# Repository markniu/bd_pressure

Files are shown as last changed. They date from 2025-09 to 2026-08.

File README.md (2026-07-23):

#  Auto PA Calibration


## Overview 

Pressure Advance (PA) is one of the most impactful tuning parameters in FDM printing, yet calibrating it correctly is time-consuming, requires print-specific expertise, and must be repeated whenever filament, speed, or temperature changes.

**bd_pressure** solves this with a dedicated strain-gauge sensor module that measures extruder pressure directly — without printing a single line. It runs an automated calibration routine by simulating extrusion pressure behaviour during acceleration and deceleration, then reports the optimal PA value to the printer firmware over USB or I2C.

The same hardware doubles as a high-precision nozzle probe for bed levelling, acting as a drop-in switch-type endstop on the Z− pin.

 
 
---

<a href="https://www.youtube.com/watch?v=r0qmRdhEHUw">
  
</a>




---

## Features

| Feature | Description |
|---|---|
| **Automatic PA calibration** | No calibration prints. Extruder-only routine measures pressure response directly. |
| **Nozzle probe** | Strain-gauge contact detection for Z homing, Z tilt, bed mesh or work with eddy bed scan sensor. |
| **EMI immunity** | Sensor mounted zero-distance to PCB — minimal analog trace length eliminates noise pickup. |
| **USB & I2C** | Flexible host connectivity; works with Klipper and compatible setups. |
| **Broad compatibility** | Mounting footprint compatible with E3D and Voron toolhead ecosystems. |

---

## How It Works

### Mode 1 — Pressure Advance Calibration

Rather than printing calibration patterns and analysing them visually, bd_pressure directly measures the mechanical relationship between extruder motor acceleration and filament pressure at the nozzle.

1. The extruder motor runs a controlled acceleration/deceleration sequence.
2. The strain gauge measures the resulting force in real time.
3. The on-board MCU fits a pressure-vs-acceleration curve and derives the optimal PA value.
4. The result is sent to the printer firmware via USB or I2C.

This approach is conceptually similar to the automated calibration used in the Bambu Lab A1, but uses a **strain gauge** rather than an eddy current sensor — providing a direct force measurement.

### Mode 2 — Nozzle Probe

bd_pressure operates as a standard switch-type endstop sensor:

1. The printer issues a normal Z homing move.
2. As the nozzle contacts the bed, the strain gauge detects the resulting force change.
3. The module asserts a signal on the endstop output — compatible with any mainboard Z− pin.
4. No additional firmware plugin is required for basic probe operation.

---

## Installation & Documentation
 
Full installation guide, wiring diagrams, and Klipper configuration reference:

 Klipper:
**[pandapi3d.cn/en/bdpressure/home](https://pandapi3d.cn/en/bdpressure/home)**

  RepRapFirmware:
**[github.com/jaysuk](https://github.com/jaysuk/bd_pressure_dwc_plugin)**






 
 The strain gauge sensor: BF350-1EB  350Ω 5.6*4.6mm 
 
---
 
## Community & Support
 
| Channel | Link |
|---|---|
| Discord | [discord.gg/z6ahddnGVU](https://discord.gg/z6ahddnGVU) |
| Facebook group | [facebook.com/groups/380795976169477](https://facebook.com/groups/380795976169477) |
| Thingiverse | [thingiverse](https://www.thingiverse.com/thing:7338066) |
| printables  | [printables](https://www.printables.com/model/1760110-a4t-cowling-variations-for-bdpressure-dragon-drago)
| Where to buy | 🇺🇸 [fabreeko.com](https://fabreeko.com) <br> 🇺🇸 [west3d.com](https://west3d.com) <br> 🌏 [pandapi3d.com](https://pandapi3d.com) <br> 🇨🇳 [淘宝](https://shop62248922.taobao.com/) <br> 🇩🇰 [3do.dk](https://3do.dk/12-abl-probe) |
---

 ### Does PA need to be calibrated during printing?

Not necessarily. Testing shows that manual calibration under actual printing conditions produces nearly the same optimal PA value as automatic calibration in free air. Back pressure and toolhead movement add noise to the pressure data, but the balance point—and therefore the optimal PA value—remains essentially unchanged.

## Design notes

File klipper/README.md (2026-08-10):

## klipper 

#### 1. Install software module
```
cd  ~
git clone https://github.com/markniu/bd_pressure.git
chmod 777 ~/bd_pressure/klipper/install.sh
~/bd_pressure/klipper/install.sh
```

#### 2. Configure Klipper

Add [include bd_pressure.cfg] into the printer.cfg , and modify the pins to your actual use in the section [probe] and [bdpressure bd_pa]

#### 3. OrcaSlicer:

1. Disable the Pressure advance in the Material settings.

2. Add the following G-code lines into the beginning of the Start_Gcode in the slicer, then it will do pressure advance calibration with your setting and automatically set the right PA value. 
```
G28                    ; Home all the axis
G1 Z30                 ; raise the nozzle above the bed
PA_CALIBRATE NOZZLE_TEMP=[nozzle_temperature] MAX_VOLUMETRIC=[filament_max_volumetric_speed] ACC_WALL=[outer_wall_acceleration]  TRAVEL_SPEED=[travel_speed]  ACC_TO_DECEL_FACTOR=[accel_to_decel_factor] NOZZLE=[nozzle_diameter] FLOW=[filament_flow_ratio]
```
`PA_CALIBRATE` only shifts the pattern's starting point to the smallest valid coordinates (x_min/y_min + `X_MARGIN`/`Y_MARGIN`, default 5 mm); the movement distances are unchanged (80 mm line = 20/40/20 mm, Y step 3.5 mm × 50 passes). This removes the old hard-coded X78/Y38.75 offset, so the same pattern fits smaller XY machines too. `NOZZLE=[nozzle_diameter]` and `FLOW=[filament_flow_ratio]` scale the extrusion amounts for your nozzle size and slicer flow ratio (the built-in E values are for a 0.4 mm nozzle at 100 % flow). NOTE: OrcaSlicer's flow-ratio placeholder is `[filament_flow_ratio]` (the config key is `filament_flow_ratio`); `[filament_flow]` only exists in PrusaSlicer and will cause "Variable does not exist" in Orca.

Manual example (run after homing / raising Z):
```
PA_CALIBRATE NOZZLE_TEMP=210 MAX_VOLUMETRIC=20 ACC_WALL=4000 TRAVEL_SPEED=400 ACC_TO_DECEL_FACTOR=50% NOZZLE=0.4 FLOW=1.0
```

If the fixed pattern still exceeds your machine (e.g. a 120 mm bed), reduce it explicitly, e.g. `PASSES=30` or `Y_STEP=2.5`:

#### 3. Prusa Slicer:
```
G28                    ; Home all the axis
G1 Z30                 ; raise the nozzle above the bed
PA_CALIBRATE NOZZLE_TEMP=[temperature] MAX_VOLUMETRIC=[filament_max_volumetric_speed] ACC_WALL=[outer_wall_acceleration]  TRAVEL_SPEED=[travel_speed]  MINIMUM_CRUISE_RATIO=0.5 NOZZLE=[nozzle_diameter] FLOW=[extrusion_multiplier] #ACC_TO_DECEL_FACTOR=[accel_to_decel_factor] this klipper specifc variable was replaced in Klipper with MINIMUM_CRUISE_SPEED. and the 0.5 is the default 50% which can be adjusted to suite the printer's capabilities. 
```
NOTE: PrusaSlicer's flow-multiplier placeholder is `[extrusion_multiplier]` (Filament → Advanced → "Extrusion multiplier", config key `extrusion_multiplier`); there is no `[filament_flow]` in PrusaSlicer.
Optional overrides: `X_MARGIN=5 Y_MARGIN=5 Y_STEP=3.5 PASSES=50` (the macro auto-fits them to the machine's travel).

#### bd_pressure.cfg considerations:
If you have both a bd_pressure and as well bd_width, each has the same by-id UUID because of this, each plugin will try and take control of the first device it can see with the UUID for the USB example 
So you would:
unplug bd_pressure usb cable, then use ls /dev/serial/by-path and take note of the entries there, then plug it back in and use the new entry that appears in place of the "ReplaceWithYourDevicePath" in the example below. 
you will only have to repeat this process if you change what port the bd_pressure is plugged into.
as well you will need to do this in bd_width.cfg as well as both devices will still show the by-id string and can still select the wrong device. 

##   usb example 
# port:usb
# serial:/dev/serial/by-id/usb-1a86_USB_Serial-if00-port0  ## uncomment this if you only have bd_pressure an no bd_width device
# serial:/dev/serial/by-path/ReplaceWithYourDevicePath  # Uncomment this if you have both bd_pressure and bd_width. You need to use ls /dev/serial/by-path , and determine which entry belongs to bd_pressure. 
#if you change the port it's plugged into, you will need to adjust this after doing so to reflect the new usb port you moved it to. 
#you also repeat this with bd_width.cfg to resolve the conflict.
# baud:38400

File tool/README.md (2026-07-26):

### BD Pressure Monitor – Quick Guide

1. Setup: Select COM port & baud (default 38400) → Connect. Auto-sends d; to start streaming.
2. Plot: Live waveform. Use Window slider for time range, toggle Auto Y scale. Pause to freeze, Clear to reset.
3. Serial Response Box: Shows all raw incoming and outgoing data (including command echo and sensor values).
4. Supported Quick Commands (BD Firmware Specific)

| Button | Command | Function |
|---|---|---|
| Endstop | e; | Switch to Endstop / Probe mode |
| Raw on | d; | Enable continuous ADC data output (sent automatically on connect) |
| Raw off | D; | Disable data output |
| PA mode | l; | Switch to Pressure Advance mode |
| Normal | i; | Set normal polarity |
| Inverted | I; | Set inverted polarity |
| Set normal | N; | Use the current reading as the baseline (zero point) |

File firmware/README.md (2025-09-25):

# Firmware Download into the sensor

1. Press and Hold on the boot button on the sensor
2. Power on the sensor with usb cable
3. Release the boot button
4. Open the STM32CubeProgrammer.exe
5. Choose the UART port and click connect button in the STM32CubeProgrammer
6. Open the firmware file for example: BD_PA20250925.hex --> Click Download
7. Finish

This process is the same as bdwidth sensor, here is the video of bdwidth: https://youtu.be/c74Q1chOo8M

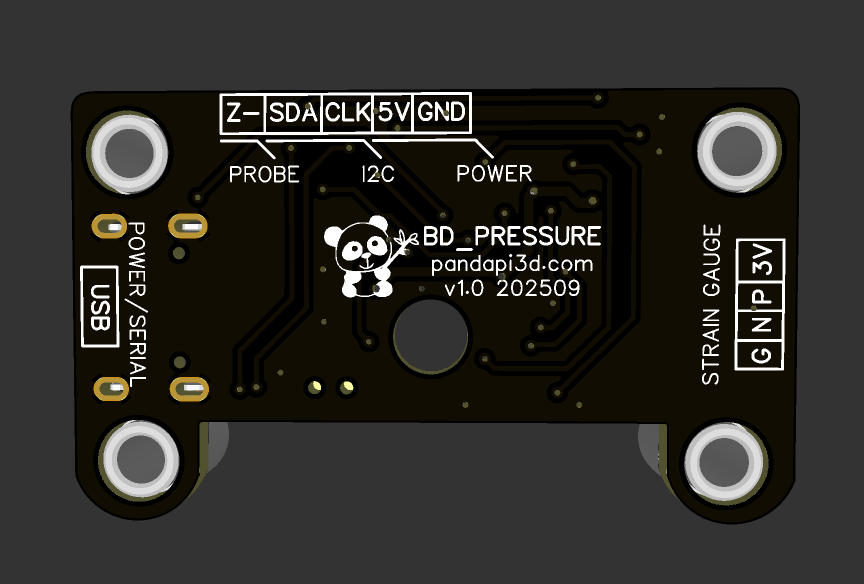
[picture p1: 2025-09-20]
hardware/pcb1.jpg

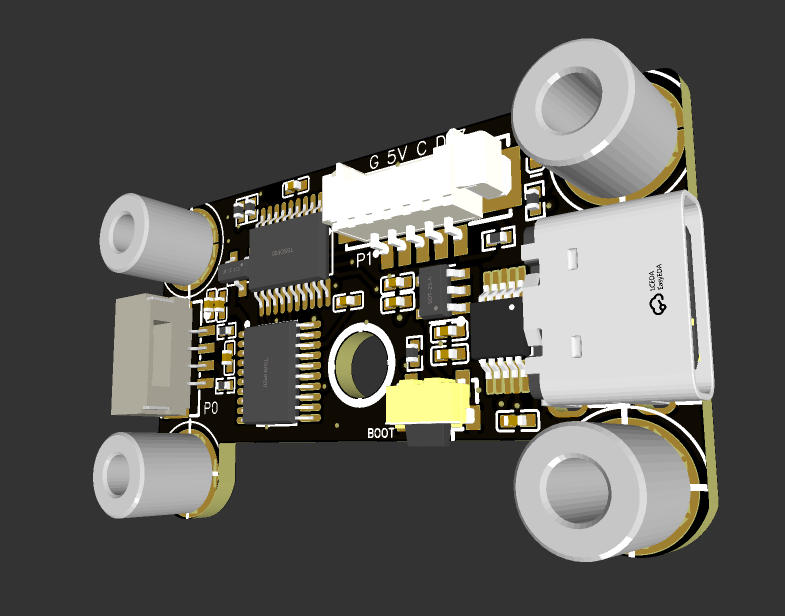
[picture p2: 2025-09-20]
hardware/pcb0.jpg

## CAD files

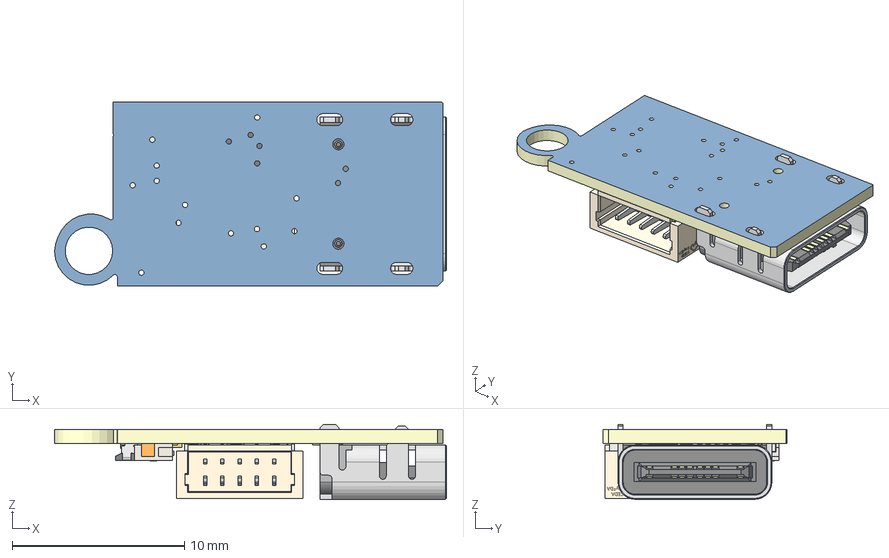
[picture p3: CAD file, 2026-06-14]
CAD/bdpressureE/bd_PCB Daughterboard only.step
22.8 x 10.7 x 4.36 mm
0402~32fe2cf9314f444ca2785a33c2db7189~xBoQ x 3
Board~xBoQ
C3~0402~32fe2cf9314f444ca2785a33c2db7189~xBoQ <1>
0402~~xBoQ
SMD,P=0.5mm,??~ddfed297a0634113a6787db35b523873~xBoQ
SMD,P=0.5mm,??~ddfed297a0634113a6787db35b523873~xBoQ_1
SMD,P=0.5mm,??~ddfed297a0634113a6787db35b523873~xBoQ_2
SMD,P=0.5mm,??~ddfed297a0634113a6787db35b523873~xBoQ_3
SMD,P=0.5mm,??~ddfed297a0634113a6787db35b523873~xBoQ_4
SMD,P=0.5mm,??~ddfed297a0634113a6787db35b523873~xBoQ_5
SMD,P=0.5mm,??~ddfed297a0634113a6787db35b523873~xBoQ_6
SMD,P=0.5mm,??~ddfed297a0634113a6787db35b523873~xBoQ_7
SMD,P=0.5mm,??~ddfed297a0634113a6787db35b523873~xBoQ_8
SMD,P=0.5mm,??~ddfed297a0634113a6787db35b523873~xBoQ_9
SMD,P=0.5mm,??~ddfed297a0634113a6787db35b523873~xBoQ_10
SMD,P=0.5mm,??~ddfed297a0634113a6787db35b523873~xBoQ_11
SMD~7b2b5bea24f944ca8310215fac973989~xBoQ
SMD~7b2b5bea24f944ca8310215fac973989~xBoQ_1
SMD~7b2b5bea24f944ca8310215fac973989~xBoQ_2
SMD~7b2b5bea24f944ca8310215fac973989~xBoQ_3
SMD~7b2b5bea24f944ca8310215fac973989~xBoQ_4
SMD~7b2b5bea24f944ca8310215fac973989~xBoQ_5
SMD~7b2b5bea24f944ca8310215fac973989~xBoQ_6
SMD~7b2b5bea24f944ca8310215fac973989~xBoQ_7
SMD~7b2b5bea24f944ca8310215fac973989~xBoQ_8
SMD~7b2b5bea24f944ca8310215fac973989~xBoQ_9
SMD~7b2b5bea24f944ca8310215fac973989~xBoQ_10
SMD~7b2b5bea24f944ca8310215fac973989~xBoQ_11
SMD~7b2b5bea24f944ca8310215fac973989~xBoQ_12
SMD~7b2b5bea24f944ca8310215fac973989~xBoQ_13
SMD~7b2b5bea24f944ca8310215fac973989~xBoQ_14
SMD~7b2b5bea24f944ca8310215fac973989~xBoQ_15
SMD~7b2b5bea24f944ca8310215fac973989~xBoQ_16
SMD~7b2b5bea24f944ca8310215fac973989~xBoQ_17
SMD~7b2b5bea24f944ca8310215fac973989~xBoQ_18
SMD~7b2b5bea24f944ca8310215fac973989~xBoQ_19
SMD~7b2b5bea24f944ca8310215fac973989~xBoQ_20
SMD~7b2b5bea24f944ca8310215fac973989~xBoQ_21
SMD~7b2b5bea24f944ca8310215fac973989~xBoQ_22
SMD~7b2b5bea24f944ca8310215fac973989~xBoQ_23
SMD~7b2b5bea24f944ca8310215fac973989~xBoQ_24
SMD~7b2b5bea24f944ca8310215fac973989~xBoQ_25
SMD~7b2b5bea24f944ca8310215fac973989~xBoQ_26
SMD~7b2b5bea24f944ca8310215fac973989~xBoQ_27
SMD~7b2b5bea24f944ca8310215fac973989~xBoQ_28
SMD,P=1mm,??~c6a442e2b039451e831f39353c9d0415~xBoQ
SMD,P=1mm,??~c6a442e2b039451e831f39353c9d0415~xBoQ_1
SMD,P=1mm,??~c6a442e2b039451e831f39353c9d0415~xBoQ_2
SMD,P=1mm,??~c6a442e2b039451e831f39353c9d0415~xBoQ_3
SMD,P=1mm,??~c6a442e2b039451e831f39353c9d0415~xBoQ_4
SMD,P=1mm,??~c6a442e2b039451e831f39353c9d0415~xBoQ_5
SMD,P=1mm,??~c6a442e2b039451e831f39353c9d0415~xBoQ_6
SMD,P=1mm,??~c6a442e2b039451e831f39353c9d0415~xBoQ_7
MSOP-10~a8ab40c7a7c54773a59b712bf86c7131~xBoQ
MSOP-10~a8ab40c7a7c54773a59b712bf86c7131~xBoQ_1
MSOP-10~a8ab40c7a7c54773a59b712bf86c7131~xBoQ_2
MSOP-10~a8ab40c7a7c54773a59b712bf86c7131~xBoQ_3
MSOP-10~a8ab40c7a7c54773a59b712bf86c7131~xBoQ_4
MSOP-10~a8ab40c7a7c54773a59b712bf86c7131~xBoQ_5
MSOP-10~a8ab40c7a7c54773a59b712bf86c7131~xBoQ_6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

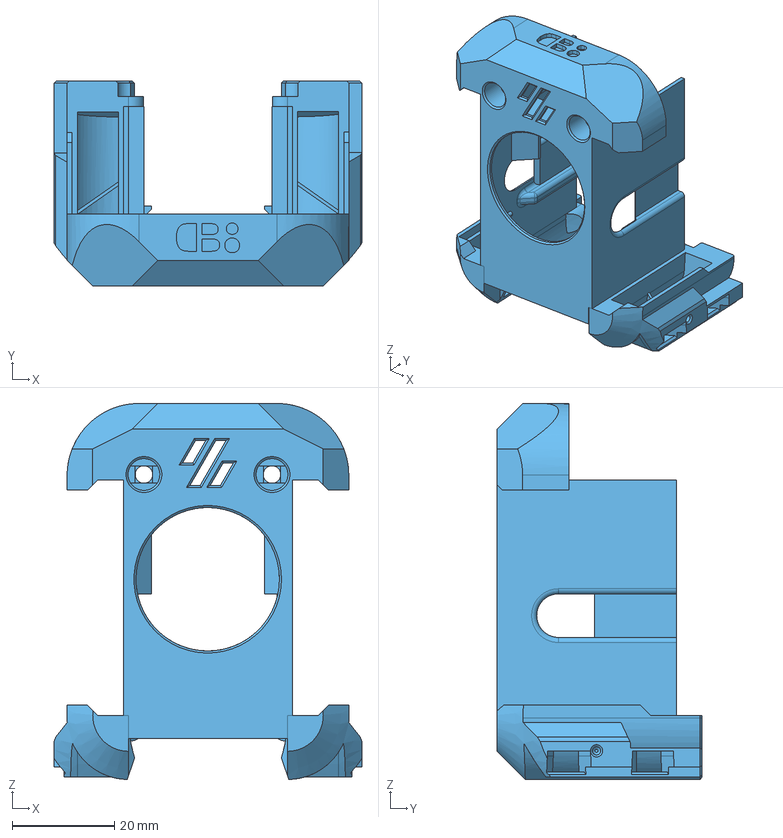
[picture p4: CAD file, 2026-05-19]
CAD/Dragon Burner Cowling By Mark Yue/BD_Pressure_DB_Cowling.step
60.1 x 40.1 x 73.4 mm

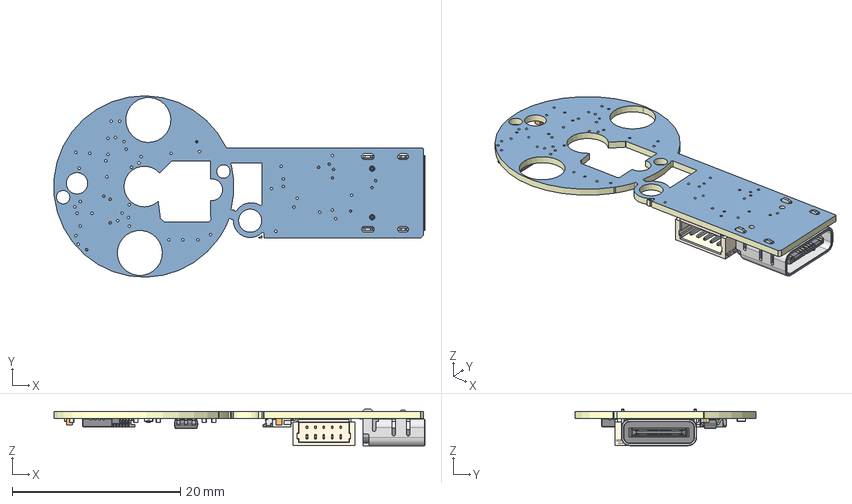
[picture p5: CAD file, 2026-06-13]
CAD/bdpressureE/bd_PCB.step
44.1 x 21.6 x 4.36 mm
0402~32fe2cf9314f444ca2785a33c2db7189~xBoQ x 9
Board~xBoQ x 2
0402~026a4a15ab5c4a92ac0e421d6d013717~xBoQ x 12
0402~~xBoQ x 2
UFQFPN-20(3x3)~ea96fbc26dda4730b9eb4e4342e704ea~xBoQ
SMD,P=0.5mm,??~ddfed297a0634113a6787db35b523873~xBoQ x 24
VQFN-16-EP(3.5x3.5)~b971549606df466cb844ddff3ea6f088~xBoQ x 31
SOT-23-5~460193f9bf2d42e58cf3c2f675b07dc6~xBoQ x 19
SMD~7b2b5bea24f944ca8310215fac973989~xBoQ x 29
SMD,P=1mm,??~c6a442e2b039451e831f39353c9d0415~xBoQ x 8
MSOP-10~a8ab40c7a7c54773a59b712bf86c7131~xBoQ x 14

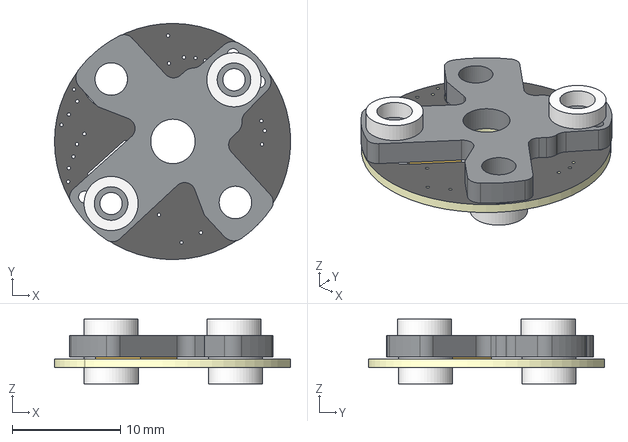
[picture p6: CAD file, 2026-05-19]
CAD/bdpressureE/bdpressure.step
21.8 x 21.8 x 6.00 mm

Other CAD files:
STLs/Dragon Burner Cowling By Mark Yue/BD_Pressure_DB_Cowling.stl

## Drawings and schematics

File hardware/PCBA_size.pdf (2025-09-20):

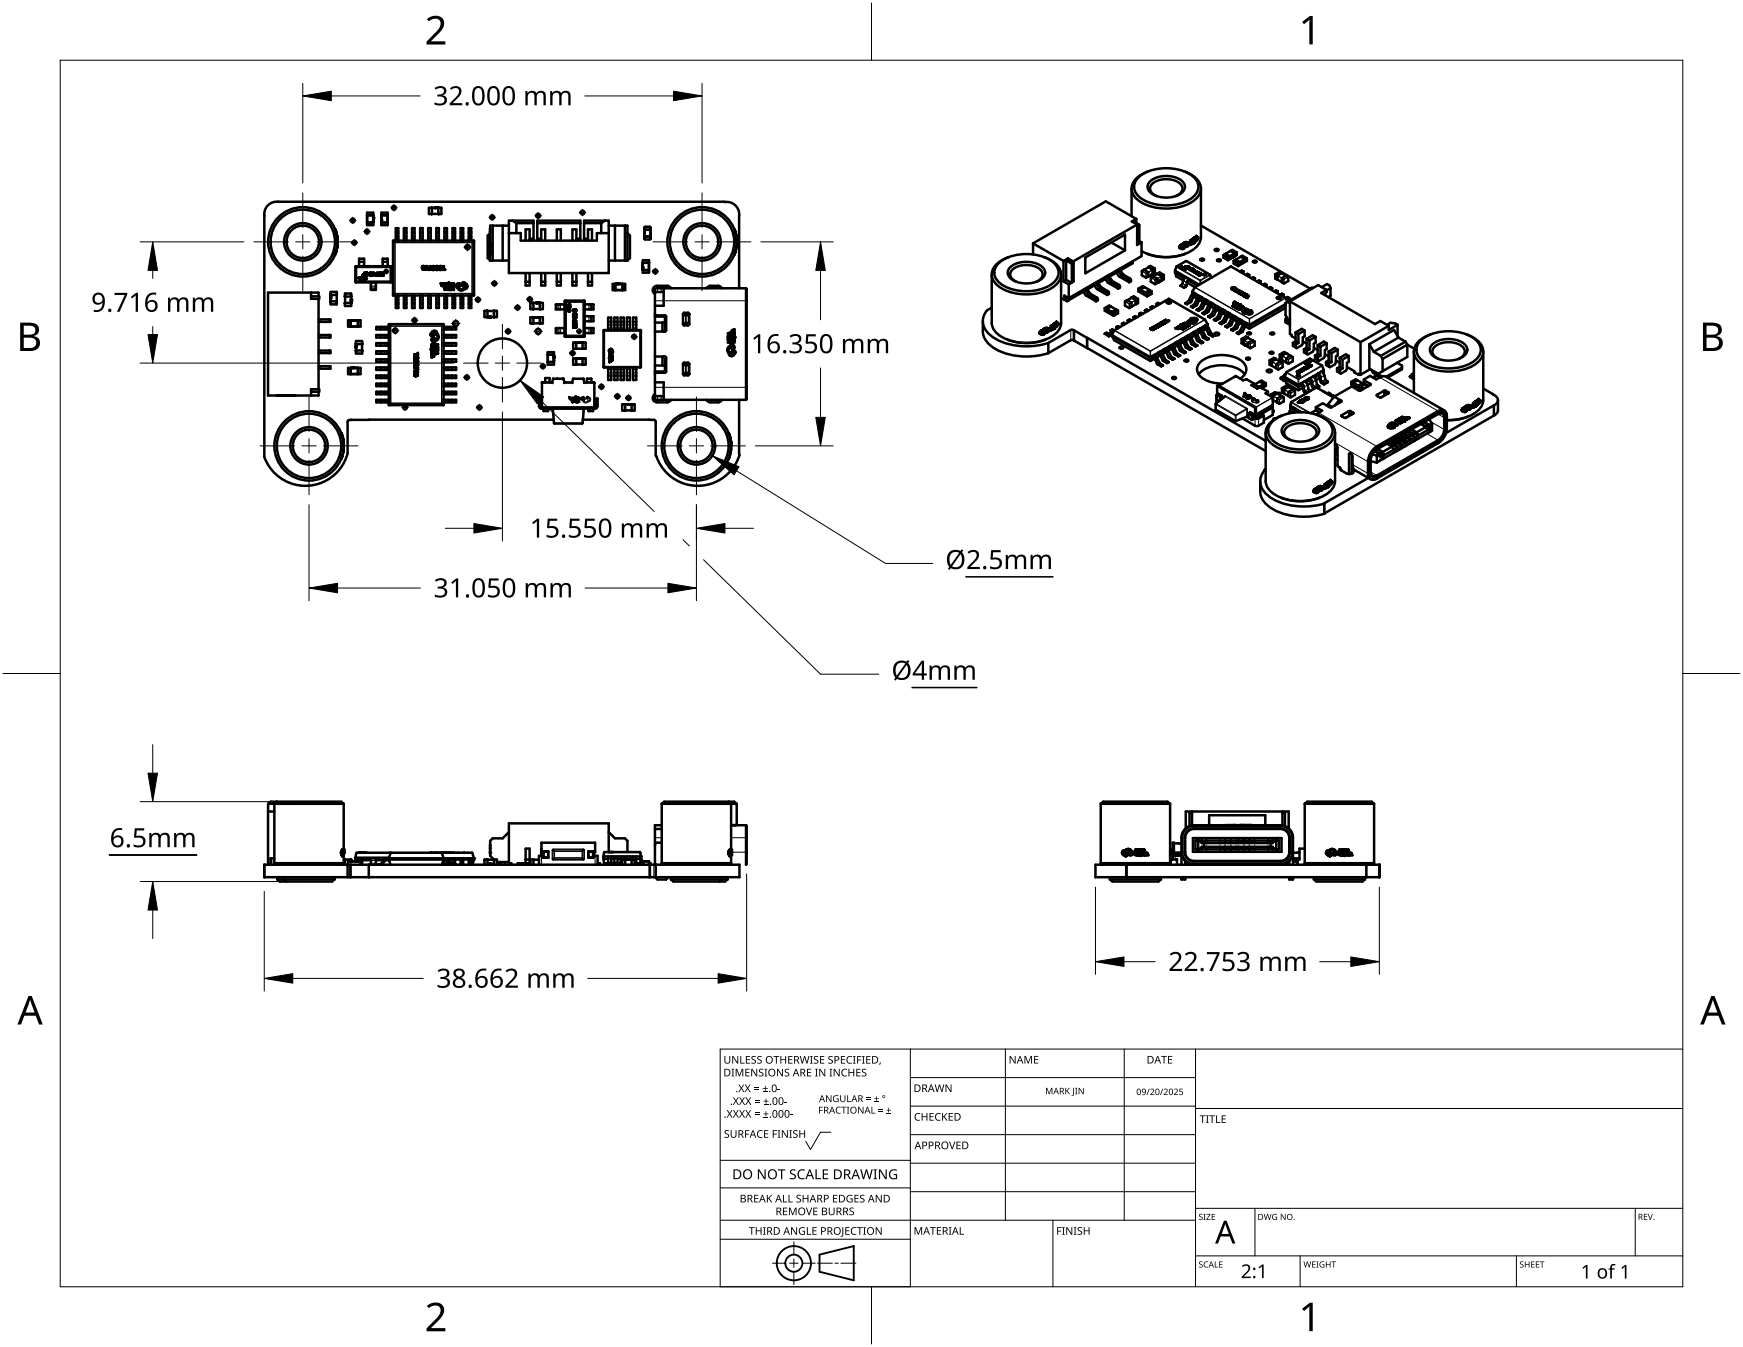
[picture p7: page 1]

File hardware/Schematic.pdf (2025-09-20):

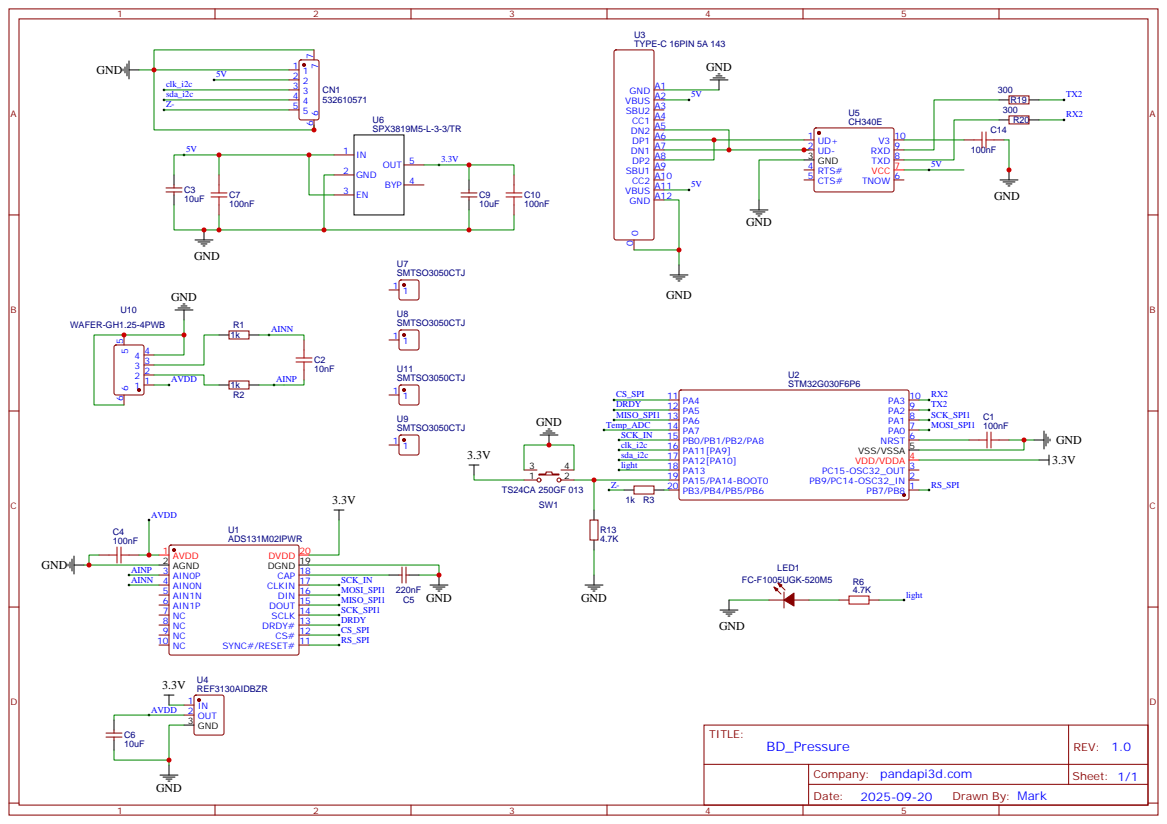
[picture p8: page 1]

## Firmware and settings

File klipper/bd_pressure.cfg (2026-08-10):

[bdpressure bd_pa]
##   usb example 
# port:usb
# serial:auto  # serial:/dev/serial/by-id/usb-1a86_USB_Serial-if00-port0
# #serial:/dev/serial/by-id/usb-1a86_USB_Serial-if00-port0  ## uncomment this if you only have bd_pressure an no bd_width device
# #serial:/dev/serial/by-path/ReplaceWithYourDevicePath  # You need to use ls /dev/serial/by-path , and determine which entry belongs to bd_pressure. if yu change the port it's plugged into, you will need to adjust this after doing so to reflect the new usb port you moved it to. 
# baud:38400

##   i2c example
port:i2c
i2c_mcu: MKS_THR
i2c_software_scl_pin:MKS_THR:PB3
i2c_software_sda_pin:MKS_THR:PB4
thrhold:3


  
[probe]
pin: ^MKS_THR:PB7
x_offset: 0
y_offset: 0
z_offset: -0.08
speed: 3
lift_speed:3
samples: 2
samples_result: median
sample_retract_dist: 5
samples_tolerance: 0.03
samples_tolerance_retries: 5
activate_gcode: 
   PA_RESET
   PA_RESET
   PA_RESET

[gcode_macro PA_RESET]
gcode:
     M400
     #G4 P200
     SET_BDPRESSURE NAME=bd_pa COMMAND=RESET_PROBE
     #G4 P200


[gcode_macro PA_STATE]
gcode:
    {% set status = printer["bdpressure bd_pa"].state %} 
    { action_respond_info("status:%s %d"%(status,params.T|int)) }


[gcode_macro PA_E]
gcode:
    # Per-step pass called by PA_CALIBRATE. All coordinates/extrusion amounts are
    # passed as params so they fit the machine build volume and the current
    # nozzle/flow scaling.
    {% set status = printer["bdpressure bd_pa"].state %}
    {% set i = params.I|int %}
    {% if status=='START' %}
        {% set pressure_ad = 0 + i*(params.STEP|float) %}
        SET_PRESSURE_ADVANCE ADVANCE={pressure_ad}
        {% set y_step = params.Y_START|float + (i*params.Y_STEP|float) %}
        G1 X{params.X_START|float} Y{y_step} F{params.T_SPEED|int}
        G1 F{params.L_SPEED|int}
        G1 X{params.X_MID1|float} Y{y_step} E{params.E_ACC|float}
        G1 F{params.H_SPEED|int}
        G1 X{params.X_MID2|float} Y{y_step} E{params.E_CRUISE|float}
        G1 F{params.L_SPEED|int}
        G1 X{params.X_END|float} Y{y_step} E{params.E_DEC|float}
        M400
        SET_BDPRESSURE NAME=bd_pa COMMAND=READ VALUE={pressure_ad}
    {% endif %}
    

[gcode_macro PA_CALIBRATE]
gcode:
    # PA_CALIBRATE NOZZLE_TEMP=[first_layer_temperature] MAX_VOLUMETRIC=[filament_max_volumetric_speed] ACC_WALL=[outer_wall_acceleration]
    # TRAVEL_SPEED=[travel_speed]  ACC_TO_DECEL_FACTOR=[accel_to_decel_factor]
    # NOZZLE=[nozzle_diameter] FLOW=[filament_flow_ratio]  # OrcaSlicer flow ratio
    # PrusaSlicer: FLOW=[extrusion_multiplier]  (Orca key = filament_flow_ratio)
    # optional: X_MARGIN=5 Y_MARGIN=5 Y_STEP=3.5 PASSES=50

    ### temperature=210,ACCEL_TO_DECEL=10000,ACCEL=8000,SQUARE_CORNER_VELOCITY=5
    {% set NOZZLE_TEMP = 210 %}
    {% if params.NOZZLE_TEMP %}
	      { action_respond_info("nozzle TEMPERATURE %s "%params.NOZZLE_TEMP) }
	      {% set NOZZLE_TEMP = params.NOZZLE_TEMP|default(210)|float %}
	  {% endif %}
    {% set ACC_WALL = 4000 %}
    {% if params.ACC_WALL %}
	      { action_respond_info("ACC_out_WALL %s "%params.ACC_WALL) }
	      {% set ACC_WALL = params.ACC_WALL|default(4000)|float %}
	  {% endif %}

    {% set SQUARE_CORNER_SPEED = 9 %}
    {% if params.SQUARE_CORNER_VELOCITY %}
	      { action_respond_info("SQUARE_CORNER_VELOCITY %s "%params.SQUARE_CORNER_VELOCITY) }
	      {% set SQUARE_CORNER_SPEED = params.SQUARE_CORNER_VELOCITY|default(9)|float %}
	  {% endif %}
    # =====================================================================
    # nozzle & flow scaling:
    #   The E values were reverse-engineered from OrcaSlicer for a 0.4mm
    #   nozzle at 100% flow (line cross-section ~0.1114 mm^2). For other
    #   nozzle diameters and/or slicer flow ratios the extrusion must be
    #   scaled:  E = E_ref * (NOZZLE/0.4)^2 * FLOW
    # =====================================================================
    {% set NOZZLE = params.NOZZLE|default(0.4)|float %}
    {% set FLOW   = params.FLOW|default(1.0)|float %}
    {% if NOZZLE <= 0 or FLOW <= 0 %}
        { action_raise_error("bd_pressure: NOZZLE and FLOW must be > 0") }
    {% endif %}
    {% set E_SCALE = (NOZZLE/0.4)**2 * FLOW %}
    { action_respond_info("nozzle %.2fmm flow %.3f E_scale %.3f"%(NOZZLE,FLOW,E_SCALE)) }

    # =====================================================================
    # machine travel: only the START point is shifted to the smallest valid
    # coordinates (x_min/y_min + margin). The movement DISTANCES are unchanged:
    # line = 20/40/20 mm (80 mm total), Y step = 3.5 mm x 50 passes.
    # =====================================================================
    {% set x_min = printer.toolhead.axis_minimum[0] %}
    {% set x_max = printer.toolhead.axis_maximum[0] %}
    {% set y_min = printer.toolhead.axis_minimum[1] %}
    {% set y_max = printer.toolhead.axis_maximum[1] %}
    {% set X_MARGIN = params.X_MARGIN|default(5)|float %}
    {% set Y_MARGIN = params.Y_MARGIN|default(5)|float %}
    {% set X_START = x_min + X_MARGIN %}
    {% set Y_START = y_min + Y_MARGIN %}

    # fixed line segments (unchanged): acc 20 / cruise 40 / dec 20 mm
    {% set L_ACC = 20.0 %}
    {% set L_CRUISE = 40.0 %}
    {% set L_DEC = 20.0 %}
    {% set X_MID1 = X_START + L_ACC %}
    {% set X_MID2 = X_MID1 + L_CRUISE %}
    {% set X_END  = X_MID2 + L_DEC %}
    {% if X_END > x_max %}
        { action_raise_error("bd_pressure: fixed 80mm line (X %.1f->%.1f) exceeds X max %.1f - machine too small"%(X_START, X_END, x_max)) }
    {% endif %}

    # fixed Y layout (unchanged): 3.5 mm step x 50 passes
    {% set Y_STEP  = params.Y_STEP|default(3.5)|float %}
    {% set PASSES  = params.PASSES|default(50)|int %}
    {% set Y_END = Y_START + (PASSES-1)*Y_STEP %}
    {% if Y_END > y_max %}
        { action_raise_error("bd_pressure: Y layout (%.1f->%.1f, step %.2f x %d) exceeds Y max %.1f - reduce PASSES or Y_STEP"%(Y_START, Y_END, Y_STEP, PASSES, y_max)) }
    {% endif %}
    { action_respond_info("line X %.1f->%.1f | Y %.1f->%.1f step %.2f passes %d"%(X_START,X_END,Y_START,Y_END,Y_STEP,PASSES)) }

    # scaled extrusion amounts (nozzle/flow only - line lengths unchanged)
    {% set E_PURGE  = 9.92204*E_SCALE %}
    {% set E_ACC    = 0.92643*E_SCALE %}
    {% set E_CRUISE = 1.85285*E_SCALE %}
    {% set E_DEC    = 0.92643*E_SCALE %}
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

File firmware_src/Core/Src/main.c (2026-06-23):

/**
  ******************************************************************************
  * @file    main.c
  * @author  Mark <markyueyue@gmail.com>
  * @version V1.0
  * @date    2026
  * @brief   Main program body – firmware entry point and core control loop.
  * @copyright Copyright (c) 2025 pandapi3d.com. All rights reserved.
  * @license This software is licensed under terms that can be found in the LICENSE file
  *          in the root directory of this software component.
  *          If no LICENSE file comes with this software, it is provided AS-IS.
  ******************************************************************************
  */
 
/* Includes ------------------------------------------------------------------*/
#include "main.h"

/* USER CODE BEGIN Includes */
#include <stdarg.h>
#include <assert.h>
#include <stdint.h>
#include <stdbool.h>
#include <stdio.h>
#include <string.h>
#include <stdlib.h>

#include "stm32c0xx_hal.h"

#include "iousart.h"
#include "pa.h"
#include "ADS1220.h"
/* USER CODE END Includes */


I2C_HandleTypeDef hi2c1;

TIM_HandleTypeDef htim1;
TIM_HandleTypeDef htim3;
TIM_HandleTypeDef htim14;

void SystemClock_Config(void);
static void MX_GPIO_Init(void);
static void MX_TIM1_Init(void);
static void MX_TIM3_Init(void);
static void MX_I2C1_Init(void);
static void MX_TIM14_Init(void);
/* USER CODE BEGIN 0 */

#define USART_TXBUFF_SIZE   128
char usart_txBuff[USART_TXBUFF_SIZE];

#define PA_OSR      7  // CLOCK_OSR_16384
#define ENDSTOP_OSR  2 //  2:CLOCK_OSR_512      1:CLOCK_OSR_256
unsigned char status_clk_old=0;
typedef struct
{

    unsigned char version[16];// pandapi3d v1.0
    unsigned char measue_data[32]; //W:1.722;D:0310;Y:-005;R:0;
    unsigned char status_clk; // endstop mode(e;)  pa mode(l;)
    unsigned char out_data_mode; // out raw data(d;), disable raw data output (D;)
    unsigned char THRHOLD_Z; // xx; E.g  12;
    unsigned char range;
    unsigned char set_normal; // 0:auto find normal_z ; 1:use current data as the normal_z ; 2: disable auto find normal_z
    unsigned char invert_data;
    // other variable

} Receive_D;

Receive_D  R_CMD;

//#define RAW_DATE_LEN 256*3

//unsigned char THRHOLD_Z=9;


// int out_data_mode = 0;

extern int r_index;
extern int normal;

int raw_dat[RAW_DATE_LEN];
int r_index=0;
int edge,read_pa=-1;
unsigned char pa_result[128];
unsigned char pa_list=0;

uint8_t rxData[64],tmp_r;
int re_index=0,re_end=0;
int normal_tmp[5]={0,0,0,0,0},normal_z=0,z_cnt=0;
unsigned int tim14_n =0 ;
int end_z=0;
void find_normal_endstop(unsigned int *r_data,int length,char force);
void USART2_printf(char *fmt,...);
void set_open(int log);

unsigned char process_cmd(void)
{
    int j=0;
    unsigned char cmd=0;
    if(sizeof(rxData)<1)
        return 1;
    for(j=1;j<sizeof(rxData);j++)
    {
        if(rxData[j]==';')
        {
            cmd = rxData[j-1];
            if(cmd=='l'){ // in pressure advance mode
                USART2_printf("PA mode\n");
                R_CMD.status_clk= PA_OSR;
            }
            else if(cmd=='e'){ // in probe mode
                USART2_printf("endstop mode\n");
                R_CMD.status_clk= ENDSTOP_OSR;
                find_normal_endstop(raw_dat,r_index,1);
            }
            else if(cmd=='d'){ // out data
                R_CMD.out_data_mode=1;
            }
            else if(cmd=='D'){ // disable data out
                R_CMD.out_data_mode=0;
            }
            else if(cmd=='i'){ // inverat the raw data
                R_CMD.invert_data=0;
            }
            else if(cmd=='I'){ //
                R_CMD.invert_data=1;
            }
            else if(cmd=='N'){ // use the current data
                R_CMD.set_normal=1;
                set_open(0);
            }
            else if(cmd=='n'){ // auto find normal_z by default
                R_CMD.set_normal=0;
            }
            else if((cmd>='0')&&(cmd<='9')){ // disable data out
                R_CMD.THRHOLD_Z=cmd-'0';
                if(j>=2){
                    if(rxData[j-2]>'0'&&rxData[j-2]<='9'){
                        R_CMD.THRHOLD_Z+=(rxData[j-2]-'0')*10;
                    }
                }
                USART2_printf("THRHOLD_Z: %d\n",R_CMD.THRHOLD_Z);
            }
            memset(rxData,0,sizeof(rxData));
            break;
        }

    }
    return cmd;
}

void USART2_printf(char *fmt,...)
{
    uint32_t i,length;
    va_list ap;
    va_start(ap,fmt);
    vsprintf(usart_txBuff,fmt,ap);
    va_end(ap);
    length=strlen((const char*)usart_txBuff);
    while((USART2->ISR&0x40)==0);
    for(i=0;i<length;i++)
    {
        iouart1_SendByte(usart_txBuff[i]);
    }
}
/*
void HAL_TIM_PeriodElapsedCallback(TIM_HandleTypeDef *htim) // 2ms
{
    if (htim->Instance == htim14.Instance)
    {
        tim14_n++;
    }
}
*/
uint8_t *ram_i2c;
uint8_t offset;
static uint8_t first_byte_state = 1;

void HAL_I2C_ListenCpltCallback(I2C_HandleTypeDef *hi2c)
{
    if (hi2c->Instance==I2C1){
        first_byte_state = 1;
        offset = 0;
        HAL_I2C_EnableListen_IT(hi2c);
    }
}

void HAL_I2C_AddrCallback(I2C_HandleTypeDef *hi2c, uint8_t TransferDirection, uint16_t AddrMatchCode)
{
    if (hi2c->Instance==I2C1){

        if(TransferDirection == I2C_DIRECTION_TRANSMIT)
        {
            if(first_byte_state)
            {
                HAL_I2C_Slave_Seq_Receive_IT(hi2c, &offset, 1, I2C_NEXT_FRAME);
            }
        }
        else
        {
            HAL_I2C_Slave_Seq_Transmit_IT(hi2c, &ram_i2c[offset], 1, I2C_NEXT_FRAME);
        }
    }
}

void HAL_I2C_SlaveRxCpltCallback(I2C_HandleTypeDef *hi2c)
{
    if (hi2c->Instance==I2C1){
        if(first_byte_state)
        {
            first_byte_state = 0;
        }
        else
        {
            offset++;
        }
        HAL_I2C_Slave_Seq_Receive_IT(hi2c, &ram_i2c[offset], 1, I2C_NEXT_FRAME);
    }
}

void HAL_I2C_SlaveTxCpltCallback(I2C_HandleTypeDef *hi2c)
{
    if (hi2c->Instance==I2C1){
        offset++;
        HAL_I2C_Slave_Seq_Transmit_IT(hi2c, &ram_i2c[offset], sizeof(Receive_D), I2C_NEXT_FRAME);
    }
}


/* USER CODE END PFP */

/* USER CODE BEGIN 0 */
/*
// ????????
void HAL_UART_RxCpltCallback(UART_HandleTypeDef *huart) {
    if (huart->Instance == USART2) {
        if( HAL_UART_Receive_IT(&huart2, &tmp_r, 1)==HAL_OK ){
                    rxData[re_index++]=tmp_r;
                    if(re_index>=sizeof(rxData))
                        re_index = 0;

             }

                //rxData[re_index]=0;
    }
}
*/

int get_ix(int i){
    if (i<0)
        i = RAW_DATE_LEN + i;
    return i;
}


void set_trigered(int log)
{
    int i=0;
    end_z=1;
    HAL_GPIO_WritePin(GPIOA,GPIO_PIN_8,GPIO_PIN_SET);
    HAL_GPIO_WritePin(GPIOA,GPIO_PIN_13,GPIO_PIN_SET);
    if(log==0)
        return;
    USART2_printf("n%d,%d\n",normal_z,R_CMD.THRHOLD_Z);
    for(i=r_index-1;i>r_index-10;i--)
        USART2_printf("%d,",raw_dat[get_ix(i)]);

}

void set_open(int log)
{
    end_z=0;
    HAL_GPIO_WritePin(GPIOA,GPIO_PIN_8,GPIO_PIN_RESET);
    HAL_GPIO_WritePin(GPIOA,GPIO_PIN_13,GPIO_PIN_RESET);
    if(log==0)
        return;
    USART2_printf("O%d\n",raw_dat[r_index-1]);

}

///////////////////////////

void find_normal_endstop(unsigned int *r_data,int length,char force)
{

    int s_avt = 0,i,min=0,max=0;
    /*  if (normal_z==0&&length>=4)
        {
            normal_z = r_data[length-1]+r_data[length-2]+r_data[length-3]+r_data[length-4];
            normal_z = normal_z/4;
            USART2_printf("n:%d\n",s_avt);
            return;
        }*/
    if(length<=31)
        return;


    min=r_data[get_ix(length-1)];
    max=r_data[get_ix(length-1)];
    for(i=length-1;i>length-1-30;i--)
    {
        if(min>r_data[get_ix(i)])
            min=r_data[get_ix(i)];
        if(max<r_data[get_ix(i)])
            max=r_data[get_ix(i)];
    }
    R_CMD.range=max-min;

    if((R_CMD.range>R_CMD.THRHOLD_Z || R_CMD.range>20)&&force==0)
        return;
    for(i=length-1;i>length-1-30;i--)
        s_avt = s_avt+r_data[get_ix(i)];
    s_avt = s_avt/30;
    if(normal_z!= s_avt)
        USART2_printf("N:%d\n",s_avt);
    normal_z= s_avt;
    tim14_n=0;

}
#define AVT_CN 4
int process_triggered(void)
{
    int s_avt = 0,i,tmp_cn=0,vibration;
    if (r_index>=RAW_DATE_LEN){
        r_index=0;
    }
    tmp_cn=2500;

    if((tim14_n%tmp_cn)==(tmp_cn-1))

    {
        tim14_n=0;
        find_normal_endstop(raw_dat,r_index,0);
    }

    for(i=r_index-1;i>r_index-1-AVT_CN;i--)
        s_avt = s_avt+raw_dat[get_ix(i)];
    s_avt = s_avt/AVT_CN;

    vibration =1;
    if(abs(s_avt-normal_z)>=R_CMD.THRHOLD_Z
            &&end_z==0 ){
        set_trigered(1);
        return 1;
    }
    else if(abs(s_avt-normal_z)<=(R_CMD.THRHOLD_Z/2)&&end_z==1){
        set_open(1);
        return 0;
    }
}


void Pressure_advance(void)
{
    if (r_index>(3*SAMPLES+1)){
        if (r_index >= RAW_DATE_LEN){
            r_index = 0;
            for(r_index=0;r_index<2*SAMPLES;r_index++)
                raw_dat[r_index] = raw_dat[RAW_DATE_LEN-2*SAMPLES-1+r_index];
            r_index = 2*SAMPLES;
            return;
        }
        find_normal(raw_dat,r_index);
        edge =has_plus(raw_dat,r_index-1*SAMPLES-5);
        if (edge > 2*SAMPLES){
            if (edge > 0){
                int ret = get_low_value(raw_dat,edge);
                if(ret>0){
                    pa_result[pa_list] = ret;
                    pa_list++;
                    r_index = 0;
                    memset(raw_dat,0,sizeof(raw_dat));
                }
            }
        }
    }

}

void Flash_OB_Handle(void) {
    FLASH_OBProgramInitTypeDef optionsbytesstruct;
    bool UPDATE = false;

    HAL_FLASHEx_OBGetConfig(&optionsbytesstruct);
    uint32_t userconfig = optionsbytesstruct.USERConfig;

    if((userconfig & FLASH_OPTR_nBOOT_SEL_Msk) != OB_BOOT0_FROM_PIN) {
        userconfig &= ~FLASH_OPTR_nBOOT_SEL_Msk;
        userconfig |= OB_BOOT0_FROM_PIN;
        UPDATE = true;
    }

    if(UPDATE) {
        optionsbytesstruct.USERConfig = userconfig;
        HAL_FLASH_Unlock();
        HAL_FLASH_OB_Unlock();
        HAL_FLASHEx_OBProgram(&optionsbytesstruct);
        HAL_FLASH_OB_Launch();
        HAL_FLASH_OB_Lock();
        HAL_FLASH_Lock();
    }
}
/* USER CODE END 0 */

/**
  * @brief  The application entry point.
  * @retval int
  */
int main(void)
{
    /* USER CODE BEGIN 1 */
    unsigned int cn_t=0,i=0;
    unsigned char cmd=0;
    int adctmp;
    int tempA;

    /* USER CODE END 1 */

    /* MCU Configuration--------------------------------------------------------*/

    /* Reset of all peripherals, Initializes the Flash interface and the Systick. */
    HAL_Init();

    /* Configure the system clock */
    SystemClock_Config();

    /* Initialize all configured peripherals */
    MX_GPIO_Init();
    MX_TIM1_Init();
    MX_TIM3_Init();
    MX_I2C1_Init();
    MX_TIM14_Init();
    /* USER CODE BEGIN 2 */
    HAL_TIM_Base_Start_IT(&htim1);
    HAL_TIM_Base_Start_IT(&htim14);
    re_index=0;
    re_end=0;
    offset=0;
    Flash_OB_Handle();
    memset(&R_CMD.version[0],0,sizeof(R_CMD));

    ram_i2c = &R_CMD.version[0];
    sprintf(R_CMD.version,"pandapi3dv1\n");
    R_CMD.THRHOLD_Z=4;
    R_CMD.status_clk=ENDSTOP_OSR;

    normal_z = 0;
    end_z = 0;
    if(HAL_I2C_EnableListen_IT(&hi2c1) != HAL_OK)
    {
        Error_Handler();
    }
    ADS1220_Init(4,0xD4);
    R_CMD.invert_data=1;
    /* USER CODE END 2 */

    /* Infinite loop */
    /* USER CODE BEGIN WHILE */
    while (1)
    {

        tempA = GetAD(4,1);
        if(PolarFlag==R_CMD.invert_data)
            tempA=-tempA;
        tempA=tempA/1000   + 6000;

        raw_dat[r_index++]=tempA;
        if(R_CMD.out_data_mode==1)
        {
            USART2_printf("%d;\n",tempA);
        }
        if(R_CMD.status_clk==PA_OSR)
            Pressure_advance();
        else
            process_triggered();
        process_cmd();
        if(R_CMD.set_normal==1||normal_z==0)
        {
            R_CMD.set_normal=2;
            find_normal_endstop(raw_dat,r_index,1);
            set_open(0);
        }
        if(status_clk_old!=R_CMD.status_clk)
        {
            status_clk_old=R_CMD.status_clk;
            if(R_CMD.status_clk==PA_OSR){
                ADS1220_Init(4,0x34);
                USART2_printf("PA mode\n");
            }
            else{
                ADS1220_Init(4,0xB4);
                USART2_printf("Endstop mode\n");
            }
        }


        /* USER CODE END WHILE */

        /* USER CODE BEGIN 3 */
    }
    /* USER CODE END 3 */
}

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


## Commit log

2025-09-25 update the klipper code
2025-09-25 upload the config file
    [bd_pressure.cfg]
2025-10-01 optimize the code
    [bd_pressure.cfg]
2026-04-16 add auto usb port detect
    [bd_pressure.cfg]
2026-05-01 Add CAD and STL Folders
    Add CAD and STL folders. Added Dragon Burner Cowling by Mark Yue
    [BD_Pressure_DB_Cowling.step, BD_Pressure_DB_Cowling.stl, bdpressure.step]
2026-05-09 fix a bug by usb communication
    [bdpressure.py]
2026-06-14 Create bd_PCB Daughterboard only.step
    [bd_PCB Daughterboard only.step]
2026-06-23 Update Thingiverse link and add Printables link
2026-06-23 add pa.c replace the pa.lib
    [ads1220.c, iousart.c, main.c]
2026-08-10 compatible with different size of nozzle, adjust extruding with flow rate
    [bd_pressure.cfg]
2026-10-14 load check firmware: I2C error recovery and a watchdog
    With Klipper's software I2C on a toolhead board a corrupted transfer could
    silence the sensor until a power cycle (seen during PA_CALIBRATE: garbage
    readings, then only empty ones). Hardening of the I2C slave:
    - register numbers past the table are ignored (reads return 0) instead of
    writing into the RAM after R_CMD,
    - every write is armed as starting with the register number, also when
    the STOP of the previous transfer was missed (before, it was never
    armed and the slave held SCL low),
    - HAL_I2C_ErrorCallback listens again after an I2C error,
    - the main loop resets I2C1 when it has not been listening, or the bus
    has been busy, f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
2026-10-14 load check: drop the 20261007 firmware, point the docs to 20261012
    The 20261012 build replaces it (same load check, plus I2C error recovery
    and a watchdog). The test results stay, marked as made with the 20261007
    build.
2026-10-15 load check firmware: fix I2C NACKs from the I2C watchdog, add diagnostics
    The 20261012 build made Klipper shut down with "I2C request to addr 4
    reports error START_NACK / NACK / START_READ_NACK", mostly at homing.
    i2c_watchdog() treated the I2C BUSY flag as a stuck bus. The flag can stay
    set (a START without STOP, e.g. from a glitch) while the slave still works,
    so I2C1 was reset about every 500 ms on an idle bus, and a request that
    landed in a reset got a NACK. Diagnostics showed 255 I2C resets within
    150 s and no sensor restart.
    - i2c_watchdog() resets I2C1 only when it has not been back in the listen
    state for 500 ms, the BUSY flag is no longer used
    - extension version 2 adds diagnosti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
2026-10-15 load check firmware: no torn two-byte reads
    A value that changed between the two bytes of a host read came out wrong,
    e.g. delta 255 instead of 0 or -256 instead of -1 (seen in BDP_CHECK_QUERY).
    put_u16() now skips the write while the host is reading (HAL state
    BUSY_TX_LISTEN). Every caller writes its value on each loop, so a skipped
    write follows about 1 ms later; check_update() now also writes peak,
    above and longest when no check is running. No extra RAM, I2C handling
    unchanged.
    Prebuilt as release_hex/BDpressureE_loadcheck_20261015b.hex (Keil, 0 errors,
    no new warnings). Not tested on hardware yet, the docs keep pointing to the
    tested 20261015 build.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
2026-11-07 klipper: nozzle collision guard, PA data fields in bdpressure_check
    bdp_guard.py (new, optional): while armed, reads chk_delta (register 64)
    every 20 ms and in stop mode shuts Klipper down when the nozzle touches
    something during homing, QGL or a mesh. New zero at every ARM, switches a
    sensor left in PA mode back to probe mode, and puts one lock on the
    sensor's I2C so the guard's timer and bdpressure.py never overlap.
    bdpressure_check.py: looks up the sensor's i2c at every use, so it goes
    through the guard's lock; reports pa_points and pa_distinct from the last
    PA_CALIBRATE so a macro can reject a calibration with bad sensor data.
    install.sh links bdp_guard.py; load_check/README.md documen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
2026-11-07 klipper/install.sh: make it executable
    Moonraker's update manager runs it as install_script after an update, and
    ./install.sh failed with Permission denied on a fresh clone.
2026-11-07 klipper/install.sh: also replace dangling links
    [ -e ] is false for a symlink whose target is gone, so the old link was
    kept and ln -s failed with "File exists", leaving Klipper without the
    module ("Section 'bdp_guard' is not a valid config section"). Remove the
    link when it is a symlink too.

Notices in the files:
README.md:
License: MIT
